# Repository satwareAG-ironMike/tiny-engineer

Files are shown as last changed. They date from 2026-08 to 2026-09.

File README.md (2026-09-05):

# Tiny Engineer

> Give your AI coding agent a body.

Tiny Engineer demo

Tiny Engineer is an open-source, 3D-printable desktop robot that physically acts out what an AI coding agent is doing: reading, thinking, coding, finishing tasks. It runs on an ESP32 over Wi-Fi and exposes a simple REST API, so any tool that can make an HTTP request can drive it.

**[Watch the demo](https://youtu.be/RX_QRxdXMjg) · [Build your own](#build-your-own) · [How it works](#how-it-works) · [API](docs/api.md)**

## Why?

AI coding agents increasingly spend long stretches working on their own. I wanted to see what mine was doing without staring at the IDE.

So I built a slightly ridiculous desk robot: instead of another spinner or status line, there is a tiny teammate sitting next to me, visibly reading, thinking, and typing while the agent works.

## How it works

How Tiny Engineer works

An AI agent works; an integration turns that into events; the robot’s REST API on your LAN receives them; the hardware moves and reacts.

**Two ways in**

- **Built-in** — Cursor Agent → Cursor hooks → `tiny-engineer-cursor` → HTTP over Wi-Fi
- **Bring your own** — Claude, Codex, or any other agent → your script/plugin/app → HTTP REST

Both hit the same Tiny Engineer REST API (`/anim`). The ESP32-C3 runs that API, robot logic, and animations, then drives:

| Bus | Hardware | Role |
| --- | --- | --- |
| I2C | PCA9685 → 5× servos | Head / neck, hands / body |
| I2C | SSD1306 OLED | Status, face, info |
| I2S | MAX98357A → speaker | Audio |

Cursor is one, sample, client, not the architecture. Details: [Cursor hooks](docs/hooks.md) · [any integration](docs/integration.md) · [HTTP API](docs/api.md)

## Build your own

End-to-end path (details live in the linked docs):

New to hardware? Start with **[From Code to Circuits](docs/hardware-for-software-engineers/README.md)** — hardware and electronics for software engineers; Tiny Engineer is the worked example.

1. **Get the electronics** — [hardware inventory](docs/hardware/components.md)
2. **3D print the parts** — [printables](3d_models/README.md)
3. **Assemble the mechanics** — fit the five servos — [3D models](3d_models/README.md), [servo axes](docs/robot-movement.md)
4. **Wire the electronics** — [wiring](docs/hardware/wiring.md), [hardware overview](docs/hardware/README.md)
5. **Flash the ESP32 firmware** — [getting started → Flash](docs/getting-started.md#4-flash)
6. **Configure Wi-Fi** — [getting started → Wi-Fi](docs/getting-started.md#5-wi-fi-setup)
7. **Test the robot** — web UI + a curl — [getting started → Prove it](docs/getting-started.md#6-prove-it)
8. **Connect your coding agent** — [Cursor hooks](docs/hooks.md) or [any IDE / REST](docs/integration.md)

Full walkthrough: [docs/getting-started.md](docs/getting-started.md).

## Hardware overview

Major pieces (exact models and counts in the BOM):

| Role | Part | Qty |
| --- | --- | --- |
| Controller | Waveshare ESP32-C3-Zero | 1 |
| Servo PWM | Adafruit PCA9685 | 1 |
| Actuators | PowerHD HD-1370A micro servos | 5 |
| Display | 0.91" 128×32 SSD1306 OLED (I2C) | 1 |
| Audio | MAX98357A + 8 Ω / 1 W speaker | 1 + 1 |
| USB / power | Adafruit 5993 USB-C breakout; **5 V / ≥2 A** supply | 1 |
| Structure | 3D-printed parts | — |

Complete inventory and limits: [docs/hardware/components.md](docs/hardware/components.md).

## Quick start

Firmware is Arduino on [PlatformIO](https://platformio.org/). From the project root:

```bash
pio run                 # build
pio run -t upload       # flash firmware + LittleFS
pio device monitor      # serial (115200)
```

If servos move but audio is silent, run `pio run -t uploadfs` once.

**Wi-Fi (first boot):** join `TinyEngineer-XXXX`, open `http://192.168.4.1/config`, enter a **2.4 GHz** network. OLED shows the setup steps.

**Web UI:** `http://tiny-engineer.local/` (or the IP on the OLED) — settings, hardware tests, animations.

**Make it move:**

```bash
curl -X POST "http://tiny-engineer.local/anim?name=ring"
```

Full route list: [docs/api.md](docs/api.md). Settings: [docs/settings.md](docs/settings.md).

## AI integrations

Anything that can `POST` over HTTP can drive the robot:

```bash
curl -X POST "http://tiny-engineer.local/anim?name=typing"
```

Useful `name` values: `typing`, `reading`, `thinking`, `ring`, `welcome`, `wakeup`, `sleep`, `attention`, `error`, `abort`, `dead`, `none`.

Cursor projects can map agent events to poses via hooks — [docs/hooks.md](docs/hooks.md). Broader patterns and examples: [docs/integration.md](docs/integration.md).

## Documentation

| Goal | Doc |
| --- | --- |
| Build end-to-end | [docs/getting-started.md](docs/getting-started.md) |
| Parts / BOM | [docs/hardware/components.md](docs/hardware/components.md) |
| Wiring / power | [docs/hardware/README.md](docs/hardware/README.md) |
| Printable parts | [3d_models/README.md](3d_models/README.md) |
| Servo axes / safe ranges | [docs/robot-movement.md](docs/robot-movement.md) |
| HTTP API | [docs/api.md](docs/api.md) |
| Settings | [docs/settings.md](docs/settings.md) |
| Cursor hooks | [docs/hooks.md](docs/hooks.md) |
| Any IDE / REST | [docs/integration.md](docs/integration.md) |
| Full index | [docs/README.md](docs/README.md) |

## Build one, break one, share it

Print it, wire it, change the CAD, swap animations, or hook up a different agent. Issues and PRs welcome — especially new integrations.

Tiny Engineer

## License

- **Software** (firmware, integrations, scripts, documentation) — [MIT](LICENSE)
- **Hardware designs** (CAD source and `.3mf` printables in [`3d_models/`](3d_models/)) — [CERN-OHL-S-2.0](3d_models/LICENSE)

See [LICENSING.md](LICENSING.md) for scope and effective date. The **Tiny Engineer** name and logo are not licensed — see [TRADEMARK.md](TRADEMARK.md).

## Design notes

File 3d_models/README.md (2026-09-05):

# 3D models

Printable parts and source CAD for the Tiny Engineer desk robot.

## Source CAD (edit / resize)

The full assembly — all components composed — lives in [`cad/TinyEngineer.f3d`](cad/TinyEngineer.f3d) (Autodesk Fusion). Open that file to adjust the model or adapt it to different hardware sizing (e.g. different servos).

## Printables

Individual parts are exported to [`parts/`](parts/) as `.3mf` files. They are ready to print in an orientation that does not need supports. Print with **PLA** or **PETG**.

Assembly uses a bunch of **2 mm diameter screws** — no glue. Easy to dismount and modify later. Exact screw lengths/counts and full assembly steps are **not documented yet**. Use the part table below, then electrical and bring-up docs.

## Parts

| File | Role |
| --- | --- |
| `Head.3mf` | Head (pitch) |
| `Neck.3mf` | Neck (yaw) |
| `HandLeft.3mf` | Left hand |
| `HandRight.3mf` | Right hand |
| `Arm.3mf` | Arm (print twice) |
| `Chest.3mf` | Chest / torso |
| `Belly.3mf` | Belly |
| `Chair.3mf` | Chair |
| `Pillow.3mf` | Chair pillow |
| `Desk.3mf` | Desk structure |
| `DeskTop.3mf` | Desk top surface |
| `DeskPad.3mf` | Desk pad |
| `LaptopCase.3mf` | Miniature laptop body |
| `LaptopScreen.3mf` | Laptop screen |
| `Bell.3mf` | Service bell |
| `LampBase.3mf` | Desk lamp base |
| `LampCap.3mf` | Lamp cap |
| `LampGlass.3mf` | Lamp glass |
| `LampButton.3mf` | Lamp button |
| `Mug.3mf` | Mug |
| `MugCoffee.3mf` | Coffee fill |
| `AiEmblem.3mf` | AI emblem detail |

## Next steps

Full build path (print → wire → flash): [docs/getting-started.md](../docs/getting-started.md).

1. Servo axes and safe ranges: [docs/robot-movement.md](../docs/robot-movement.md)
2. Wiring and power: [docs/hardware/wiring.md](../docs/hardware/wiring.md), [docs/hardware/README.md](../docs/hardware/README.md)
3. Bring-up and failures: [docs/hardware/testing.md](../docs/hardware/testing.md)

## License

CAD source (`.f3d`) in [`cad/`](cad/) and printable parts (`.3mf`) in [`parts/`](parts/) are licensed under [CERN-OHL-S-2.0](LICENSE). See [NOTICE](NOTICE) for copyright, Source Location, and product notice requirements.

Commercial use is allowed. If you modify and distribute Products based on these designs, reciprocal provisions require sharing your Complete Source under the same license. This documentation file is software documentation and remains under the MIT License — see [LICENSING.md](../LICENSING.md).

The **Tiny Engineer** name and logo are not licensed — see [TRADEMARK.md](../TRADEMARK.md).

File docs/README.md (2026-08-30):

# Docs index

Pick a path. Depth lives in the linked pages.

| You want to… | Start here |
| --- | --- |
| **Bridge into hardware/electronics** (software engineer background) | [hardware-for-software-engineers/README.md](hardware-for-software-engineers/README.md) |
| **Build from scratch** (parts → print → wire → flash) | [getting-started.md](getting-started.md) |
| **Use with Cursor** (robot already on Wi‑Fi) | [getting-started.md](getting-started.md) → [hooks.md](hooks.md) |
| **Flash / configure** only | [getting-started.md](getting-started.md)#4-flash |
| **Wire / power detail** | [getting-started.md](getting-started.md)#3-wire-and-power → [hardware/README.md](hardware/README.md) |
| **Print / parts inventory** | [getting-started.md](getting-started.md)#2-print-and-mechanical → [../3d_models/README.md](../3d_models/README.md) |
| **HTTP API / settings** | [api.md](api.md); add a setting: [settings.md](settings.md) |
| **Any IDE / scripts** | [integration.md](integration.md) |

Also: [robot-movement.md](robot-movement.md) (servo axes and safe ranges).

**Source of truth:** pin constants in firmware (`include/pins.h`); electrical detail in `docs/hardware/`; HTTP shapes in [api.md](api.md).

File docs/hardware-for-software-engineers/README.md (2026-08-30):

# From Code to Circuits: Hardware for Software Engineers

*Learn electronics and physical builds through Tiny Engineer — a desk robot that's fun to finish and honest about real hardware.*

I wrote this because software engineers keep asking how to build Tiny Engineer when they've never touched the hardware side — what's a servo driver, why two voltages, whether they'll destroy the board on first power-on. The build docs tell you *what to connect*; this guide answers the questions behind them.

---

## Goal

**Bring the world of electronics and hardware closer to software engineers** — especially the ones showing up with Tiny Engineer parts and no hardware background.

If you live in code, hardware docs can feel like a foreign API with no types and no stack traces. This guide closes that gap: same systems thinking you already use — buses, power budgets, failure modes — applied to volts, GPIO, and printed plastic. It's the long-form version of answers I give when someone says *"I'm a developer, I just want the robot to work."*

**Why now:** AI makes writing code fast and cheap. Hardware stays tangible, constrained, and extremely satisfying when something on your desk actually moves because *you* wired it.

**Why Tiny Engineer as the example:** one coherent stack (MCU, I2C, I2S, power domains, 3D print, servos) — real enough to teach honest hardware, bounded enough to finish if you stick with it. It also ties back to software via Wi-Fi and HTTP, which helps the mental bridge.

**What you'll get out of it:** read datasheets, schematics, and embedded docs without feeling like an outsider — whether you build this robot or the next board on your bench.

**Honest expectation:** Tiny Engineer was never meant to be an entry-level electronics kit (no single-LED breadboard tutorial). Overall difficulty is **medium**. It can still be your **first hardware project** as a software engineer — if you read first, bench-test before closing the shell, and don't treat "first" as "trivial." See [difficulty by area](#honest-difficulty-by-area) below.

---

I'm a software engineer. I got into hardware and electronics long before Tiny Engineer — out of curiosity, because I find it fun, and because making something *physical* work hits different from shipping another service. I'm not an EE. I've smelled the regret breadboard too; I've also had plenty of projects since then that actually moved and blinked.

Tiny Engineer is one project in that line. I'd recommend this path to any software engineer: learn the basics, wire something on a bench, watch it do a thing you commanded. Especially now, when a servo buzzes because you misaligned a horn — not because a model hallucinated a pin number — you learn something no codegen session replaces.

**What this is:** a bridge into electronics, microcontrollers, power, protocols, and mechanical build craft — taught with software-engineer mental models.

**What this is not:** only a Tiny Engineer assembly manual. When you're ready to wire and flash step by step, use [getting-started.md](../getting-started.md) and the [hardware reference](../hardware/README.md).

---

## Why Tiny Engineer is the example

Every chapter teaches a **general concept**, then shows **where it lands in this build**. Tiny Engineer gives you real constraints — 3.3 V vs 5 V domains, shared I2C, offloaded servo PWM, print tolerances, antenna keep-out — without throwing you into a parts warehouse with no narrative. Finish the robot if you want the payoff; the vocabulary transfers to other ESP32, Arduino, or IoT projects either way.

It's a good **first hardware project for a software engineer**. It is **not** a good **first project in electronics** in the abstract — compare it to a blinking-LED kit and this is several notches up. This guide exists because those two truths collide constantly in questions from SWEs who want to build the robot anyway.

---

## Honest difficulty by area

Rough levels: **Easy** · **Medium** · **Medium–High** (for someone with no prior hardware builds). Overall build: **Medium**.

| Area | Level | Why |
| --- | --- | --- |
| [Electricity & power domains](01-electricity-and-units.md) | Medium | Two voltage rails, common GND, VCC vs V+ — mistakes fry boards, not just fail tests |
| [Microcontrollers & ESP32](02-microcontrollers-and-esp32.md) | Medium | Wi-Fi MCU, native USB, scarce GPIO, flash/LittleFS — more moving parts than Arduino Uno 101 |
| [Wiring & schematics](03-wiring-craft-and-schematics.md) | Medium–High | Six-ish modules, many nets, classic traps (swapped I2C, speaker on GND) |
| [Buses: I2C, I2S, PWM](04-buses-and-protocols.md) | Medium | Three protocol types in one device; standard hobby stack, but not "one wire one LED" |
| [Servos & mechanical motion](05-servos-and-mechanical-motion.md) | Medium–High | Five joints, horn alignment, mechanical limits, binding/stall — software clamps can't fix physics |
| [3D printing & mechanical build](06-3d-printing-and-mechanical-build.md) | Medium | Many printed parts, tolerances, partial assembly docs; optional Fusion edits add learning curve |
| [Power budgets & safety](07-power-budgets-and-safety.md) | Medium | Real stall currents (~1.3–1.6 A), supply sizing, brownout debugging |
| [Embedded workflow & debug](08-tools-debugging-and-embedded-workflow.md) | Medium *(lower if you live in CLI)* | PlatformIO, serial, bisect bring-up — familiar shape for SWEs, unfamiliar failure modes |
| REST / Wi-Fi / agent hooks | Easy *(for SWEs)* | HTTP you already know — **after** hardware works |

**What makes it medium, not beginner-kit:**
- Multiple ICs on shared buses, not one chip
- Motor power + logic power discipline
- Mechanical assembly with real tolerances
- Debug requires dividing hardware vs software

**What makes it viable as a first SWE hardware project:**
- Documented BOM, wiring, firmware — not a blank breadboard
- Software-shaped affordances: serial logs, HTTP `/test/*`, web UI
- This guide translates concepts into your vocabulary first
- Finish line is motivating (desk robot, not only a blinking LED)

If you've never touched a multimeter, budget extra time on [Ch. 01](01-electricity-and-units.md), [Ch. 07](07-power-budgets-and-safety.md), and bench bring-up in [Ch. 08](08-tools-debugging-and-embedded-workflow.md). Skipping straight to "assemble everything and flash" is how medium projects feel hard.

---

## Who should read this

**Read this if you:**
- Write code for a living and want to build Tiny Engineer (or similar) without a hardware background
- Got the parts or the repo and hit questions the assembly docs don't pause to explain
- Know what HTTP is but not what I2C is
- Can follow a tutorial but want to understand what you're doing
- Are curious about embedded, IoT, or physical computing — even if you've never soldered

**Skip this if you:**
- Already own a multimeter and use words like "pull-up" without Googling
- Have built an ESP32 project before and just need the BOM — go to [getting-started.md](../getting-started.md)

**Don't skip the difficulty section** if this is your first hardware build — [Honest difficulty by area](#honest-difficulty-by-area) sets expectations.

---

## How this fits the rest of the docs

There are three layers. Read them in order when you're learning; jump to the right layer when you know what you need.

```mermaid
flowchart LR
  primer["hardware-for-software-engineers\n(concepts)"]
  build["getting-started.md\n(steps)"]
  ref["hardware/\n(reference)"]

  primer -->|"understand why"| build
  build -->|"look up details"| ref
```

| Layer | When to use it |
| --- | --- |
| **This guide** | Bridging hardware/electronics concepts from a software background |
| **[getting-started.md](../getting-started.md)** | Doing the build step by step |
| **[hardware/](../hardware/README.md)** | Looking up pins, wiring, power numbers, test procedures |

---

## Reading order

**Full path** (recommended if hardware is new to you):

1. [Electricity and units](01-electricity-and-units.md)
2. [Microcontrollers and ESP32](02-microcontrollers-and-esp32.md)
3. [Wiring craft and schematics](03-wiring-craft-and-schematics.md)
4. [Buses and protocols](04-buses-and-protocols.md)
5. [Servos and mechanical motion](05-servos-and-mechanical-motion.md)
6. [3D printing and mechanical build](06-3d-printing-and-mechanical-build.md)
7. [Power budgets and safety](07-power-budgets-and-safety.md)
8. [Tools, debugging, and embedded workflow](08-tools-debugging-and-embedded-workflow.md)
9. [How it all fits together](09-how-it-all-fits-together.md)

**Shortcuts** — where universal concepts land in this build; jump to one chapter if you only need that topic:

| You need to understand… | Read |
| --- | --- |
| ESP32-C3-Zero, GPIO, USB, antenna | [Ch. 02](02-microcontrollers-and-esp32.md) |
| 3.3 V vs 5 V, LDO, VCC vs V+ | [Ch. 01](01-electricity-and-units.md) + [Ch. 07](07-power-budgets-and-safety.md) |
| I2C (OLED + PCA9685) | [Ch. 04](04-buses-and-protocols.md) |
| I2S (audio) | [Ch. 04](04-buses-and-protocols.md) |
| Servo PWM chain | [Ch. 04](04-buses-and-protocols.md) + [Ch. 05](05-servos-and-mechanical-motion.md) |
| Fusion CAD edits | [Ch. 06](06-3d-printing-and-mechanical-build.md) |
| PLA vs PETG | [Ch. 06](06-3d-printing-and-mechanical-build.md) |

---

## Mini glossary

Terms you'll see everywhere. Each chapter goes deeper. Think of these as hardware concepts translated into software-shaped words.

| Term | One-line meaning |
| --- | --- |
| **MCU** | The chip that runs your firmware — like a tiny server that boots straight into one binary (no OS, no SSH). Here: ESP32-C3 |
| **GPIO** | A pin the firmware can drive or read — hardware I/O endpoints, not USB or Wi-Fi |
| **GND** | Shared **0 V reference** for every module — like agreeing on one clock/time base; without it, nothing can talk reliably |
| **3.3 V / 5 V** | **Signal voltage** (3.3 V, ESP32-safe) vs **power rail** (5 V, servos/amp) — two different numbers; don't mix them up |
| **LDO** | Onboard **5 V → 3.3 V converter** for logic chips — sized for milliamps, not motors |
| **I2C** | Two-wire **request/response bus** — each chip has an address (`0x40`, `0x3C`); ESP32 is the only master |
| **I2S** | **Streaming audio bus** — continuous PCM samples over wires, like a one-way socket, not I2C-style reads |
| **PWM** | A pin toggling on/off on a schedule — servos read **pulse length** inside each cycle as "go to this angle" |
| **Brownout** | Power sags → chip **hard-resets** — feels like a random reboot, often when servos or audio spike current |
| **PCA9685** | **Servo PWM co-processor** — ESP32 sends angles over I2C; this chip generates the precise 50 Hz pulses |

---

## When you're ready to build

You've read enough when you can explain in plain language:

- Why servos don't get power from the ESP32's 3.3 V pin
- What I2C and I2S do on this robot (and that they're different)
- Why there's a separate PCA9685 chip instead of "just PWM in code"
- Where the ceramic antenna is and why you shouldn't bury it in plastic

Then open [getting-started.md](../getting-started.md) and work through parts → print → wire → flash → Wi-Fi → prove it.

**Reference:** [getting-started.md](../getting-started.md) · [hardware/README.md](../hardware/README.md) · [3d_models/README.md](../../3d_models/README.md)

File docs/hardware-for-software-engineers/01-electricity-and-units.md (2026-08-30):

# Electricity and units

Before you touch a wire, you need a shared vocabulary. Hardware docs throw around V, A, Ω, and GND like everyone took a circuits class. You didn't — that's fine. This chapter gets you to "I know what could kill my board." Every embedded project has power rails and a common ground; Tiny Engineer is a clear example of **two voltage domains** on one USB cable.

---

## Voltage, current, resistance, power

Four quantities. You'll see them on every datasheet.

| Quantity | Unit | What it means (intuition) |
| --- | --- | --- |
| **Voltage (V)** | Volts | Electrical "pressure" — how hard electrons are being pushed |
| **Current (I)** | Amperes (amps) | Flow rate — how many electrons per second |
| **Resistance (R)** | Ohms (Ω) | How much something resists flow |
| **Power (P)** | Watts (W) | Energy used per second — P ≈ V × I |

> **If you've written backend code…** Voltage is like request pressure on a queue. Current is throughput. Resistance is backpressure. Power is your AWS bill when both spike at once.

**Ohm's law** (you don't need to derive it): V = I × R. If you push harder (more V) through the same resistance, more current flows. Thin wire = more R = less I for the same V.

---

## DC vs AC

**DC (direct current):** voltage stays one way, like a battery. Tiny Engineer runs on **5 V DC** from USB.

**AC (alternating current):** voltage flips direction — wall outlets, 50/60 Hz. Not relevant inside the robot except that your USB charger converts AC to DC before the robot ever sees it.

---

## What "ground" (GND) actually is

GND is not a magical sink into the earth. It's a **shared reference point** that every device agrees is "zero volts."

All signals are measured *relative to GND*. If two boards don't share GND, their "high" and "low" mean nothing to each other — like two services with no common schema.

**Rule:** Connect all GND pins together. One common ground net for the whole robot.

---

## Series and parallel (just enough)

**Series:** components in a chain — same current flows through all of them.

**Parallel:** components side by side — same voltage across each branch; current splits.

Your five servos are **parallel** on the 5 V rail: each gets 5 V, and current adds up. That's why five servos can pull ~1.3 A together and overwhelm a weak USB port.

---

## Shorts, reversed polarity, and smoke

Three ways beginners destroy boards. Each is a **wiring mistake**, not a firmware bug — the code may never run.

### Short circuit — power wired straight to ground

**What it is:** `+5V` and `GND` connected with **almost no resistance** between them — a bare wire, a loose strand, a metal tool, a solder bridge.

**What happens:** Current spikes (Ohm's law: low R → huge I). Wires heat. USB port or regulator shuts off — or something burns. The chip may die instantly.

**What it looks like:** Instant. Sometimes smell. Board never boots. Multimeter beep between 5V and GND *before* power-on = stop and fix wiring.

> **Software analogy:** Like routing all traffic to `/dev/null` with infinite concurrency — the system doesn't degrade gracefully; something upstream trips hard.

**Common causes while wiring:** twisted red/black leads, frayed insulation, screwdriver slip, VCC accidentally tied to GND on a breakout.

### Reversed polarity — + and − swapped

**What it is:** Power connected **backwards** — positive where ground should be, ground where positive should be.

**What happens:** Depends on the board. Some breakouts have protection diodes; many don't. Best case: nothing until you fix it. Worst case: dead regulator, dead MCU, dead module.

**Rule:** Match labels on the diagram (`5V`, `VCC`, `Vin`, `GND`). Red-ish often means positive; black/brown often means ground — **verify**, don't guess from habit alone.

> **Don't "test" reversal on purpose.** Fix orientation before first power-on.

### Logic overvoltage — 5 V on a 3.3 V GPIO pin

**What it is:** Driving **5 V into an ESP32 GPIO** that only tolerates **3.3 V**. Different from powering the whole board at 5 V through its proper **5V** input pad (that path goes through the onboard regulator).

**What happens:** Input protection may clamp once; repeated or sustained overvoltage **damages the pin or the chip**. Behavior becomes erratic; pin may die silently.

**On Tiny Engineer:** I2C, I2S, and servo **signal** lines are 3.3 V logic. Servo **motor power** is 5 V on the red wire — that goes to PCA9685 **V+**, not to an ESP32 GPIO.

> **Software analogy:** Sending a payload the parser never validated — undefined behavior, often permanent. No try/catch on the silicon.

### Quick reference

| Mistake | You literally did | Typical result |
| --- | --- | --- |
| **Short** | Connected +5V to GND directly | Huge current, heat, dead supply path or board |
| **Reversed polarity** | Swapped power + and − on a module | Dead module or MCU — may be instant |
| **Logic overvoltage** | 5 V signal into ESP32 GPIO / 3.3 V input | Damaged pin or chip — flaky then dead |

**Before first power-on:** visual check, then continuity test (power **off**) — no beep between 5V and GND; every module's GND tied together. Assembly checks: [wiring.md](../hardware/wiring.md).

---

## 3.3 V, 5 V, and ones and zeros

In code you think in **bits**: `0` and `1`, `true` and `false`, `LOW` and `HIGH`. On a GPIO pin that is **not abstract** — the chip **holds the wire at a voltage** relative to GND:

| Logic (firmware) | Typical voltage on ESP32 pin | Meaning |
| --- | --- | --- |
| **0** / `LOW` / `false` | ~**0 V** (near GND) | "Pull the line down" |
| **1** / `HIGH` / `true` | ~**3.3 V** | "Pull the line up" |

So **3.3 V is the "one" voltage** on this robot's logic wires. A **zero** is not a separate negative voltage — it's "close enough to ground."

> **If you've written backend code…** GND is 0.0; a logic **1** is ~3.3 — like a boolean with a defined numeric encoding on the wire. I2C and I2S don't send JSON; they toggle and stream voltages that the other chip interprets as bits.

### Two different jobs — don't confuse them

| | **3.3 V (logic domain)** | **5 V (power domain)** |
| --- | --- | --- |
| **Role** | Encode **0s and 1s**; run logic chips at their rated voltage | **Deliver energy** — motors, audio amp, board power input |
| **On Tiny Engineer** | ESP32 GPIO, I2C (SDA/SCL), I2S (BCLK/LRC/DIN), servo **signal** wires, **VCC** on PCA9685/OLED | Servo **motor** power (red wire → PCA9685 **V+**), MAX98357A **Vin**, ESP32 **5V** input pad |
| **Current** | Milliamps per pin / tens of mA on a **VCC** rail | Up to **~1.5 A** when servos stall |

**VCC** on a breakout (3.3 V) = "power this chip's brain so it can read and drive ones and zeros." It is **not** the same net as the 5 V that spins a servo.

**5V** on the ESP32 board = "feed the module" — an onboard **LDO** drops that to 3.3 V so the chip's core and GPIO speak the right logic levels.

### What goes wrong if you mix them up

- **5 V on a GPIO / I2C / I2S line** — you're forcing a **"one" louder than the chip allows** (~3.3 V max on ESP32). Damage. See **Logic overvoltage** above.
- **Servo motor power from 3.3 V** — the line can't supply enough **current** to move metal; brownout or dead regulator. Signal wire at 3.3 V PWM is fine; **power** wire needs 5 V.

When you read `digitalWrite(pin, HIGH)` in firmware, picture **~3.3 V on that pin**. When you read a schematic's **3V3** net, picture **the rail that defines what a "one" looks like** for every chip tied to it.

---

## Two voltage domains (the idea)

Real boards rarely run everything at one voltage. You'll see:

- A **power rail** (often 5 V) for things that need muscle — motors, amplifiers
- A **logic rail** (3.3 V) where **ones and zeros live** — GPIO, I2C, I2S, chip **VCC**

They share GND (that's your **zero**). They do **not** share the same positive rail unless a regulator explicitly converts between them.

---

## In Tiny Engineer

This robot is a textbook example of **two domains on one USB cable**.

```mermaid
flowchart TB
  USB["USB 5V"]
  subgraph fiveV [5V domain]
    ESP5[ESP32 5V in]
    PCApwr[PCA9685 5V and V+]
    MAXvin[MAX98357A Vin]
    SERVOS[Servo motors]
  end
  subgraph threeV [3.3V logic domain]
    ESPcore[ESP32 GPIO and core]
    PCAlogic[PCA9685 VCC]
    OLED[OLED VCC]
  end
  USB --> fiveV
  ESP5 --> ESPcore
  ESPcore --> threeV
  PCApwr --> SERVOS
```

**5 V domain** — USB comes in through the Adafruit 5993 breakout and feeds:
- ESP32 **5V** input (then an onboard LDO drops to 3.3 V for the chip)
- PCA9685 **5V** and **V+** (servo motor power)
- MAX98357A **Vin** (audio amp)

**3.3 V domain** — the ESP32's LDO generates the rail where **logic 1 = ~3.3 V** and **logic 0 = ~0 V**:
- ESP32 core and GPIO (your `HIGH` / `LOW` in code)
- PCA9685 **VCC** (chip logic + I2C — reads 0/1 on SDA/SCL)
- OLED **VCC** (display logic on the same I2C bus)

### The mistake that costs boards

The PCA9685 has **VCC** (3.3 V logic) and **V+** (5 V servo power). They must stay **separate**. Beginners jumper them because both say "power." Don't. You feed motor current into logic circuits or starve servos of voltage.

### Never power servos from 3.3 V

Five HD-1370A servos at stall draw on the order of **1.3–1.6 A**. The ESP32's LDO is rated for hundreds of mA of *logic*. Plug servos into 3.3 V and you get brownout, reset, or a dead regulator. Servos get 5 V via PCA9685 **V+**; the signal wire is 3.3 V PWM from the driver — that's fine.

### Common GND

Every module — ESP32, PCA9685, OLED, amp, servos — ties GND to the same net. Power without shared GND is like deploying microservices that can't reach each other's network.

Full stall math and symptom tables: [power.md](../hardware/power.md).

---

**Next:** [Microcontrollers and ESP32](02-microcontrollers-and-esp32.md)

**Reference:** [hardware/power.md](../hardware/power.md) · [hardware/wiring.md](../hardware/wiring.md)

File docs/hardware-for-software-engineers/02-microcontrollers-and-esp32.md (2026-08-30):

# Microcontrollers and ESP32

Your laptop runs Linux, Chrome, and seventeen Slack notifications. A microcontroller runs *one program*, forever, with no OS you recognize. That gap — between "real computer" and "chip that drives GPIO" — is where most software engineers stall. This chapter closes it. Tiny Engineer uses an **ESP32-C3** as its instance; the ideas apply to Arduino, STM32, and most hobby boards.

---

## MCU vs SBC vs your laptop

| | Microcontroller (MCU) | Single-board computer (SBC) | Laptop |
| --- | --- | --- | --- |
| Examples | ESP32, Arduino, STM32 | Raspberry Pi, BeagleBone | What you're reading this on |
| OS | Bare-metal or RTOS; often "Arduino" | Full Linux | Full OS |
| Boot time | Milliseconds | Seconds | Minutes if updates pending |
| GPIO pins | Yes, direct | Yes, but often through OS layers | Basically no |
| Real-time I/O | Designed for it | Possible, awkward | Not the point |
| Power | Milliwatts to low watts | Watts | Tens of watts |

Tiny Engineer needs Wi-Fi, five servos, a display, and audio on a desk robot budget. An MCU with built-in radio fits. A Pi would work but adds OS overhead, boot time, and power for no gain here.

---

## What firmware is

**Firmware** is the program stored in flash on the chip. It runs on boot. There's no `git pull` on the device — you **build** on your computer and **upload** (flash) the binary over USB.

> **If you've written backend code…** Flashing firmware is deploying a single static binary to a device with no package manager. Serial monitor is `stdout`. There's no SSH — you re-flash or use HTTP once Wi-Fi works.

**Flash** = non-volatile storage (survives power-off). Holds your program and, on this project, LittleFS files (WAV sounds).

**RAM** = working memory. Much smaller than flash. Gone on reboot.

---

## GPIO — the hardware API

**GPIO** (General Purpose Input/Output) pins are wires the firmware controls or reads. On the wire that is literally **zeros and ones** as voltages (see [Ch. 01](01-electricity-and-units.md)):

- **Output HIGH / 1** ≈ 3.3 V on that pin (on ESP32)
- **Output LOW / 0** ≈ 0 V (GND)
- **Input** — read whether the other side is holding the line high or low

Blink an LED? Firmware toggles one pin between 0 and 1. Same idea scales up: **communication protocols are patterns of zeros and ones on one or more pins over time** — serial (UART), I2C, SPI, I2S, even USB on this chip. Libraries hide the bit timing; underneath it's still GPIO-level signaling.

You don't get unlimited pins. Each pin might be reserved for flash, USB, or boot strapping. Scarcity is real — see [pinout.md](../hardware/pinout.md) for the full map.

---

## Boot, reset, and upload

**RESET** — reboots the chip (like killing and restarting a process).

**BOOT** — strapping pin; hold during reset to enter serial upload mode if auto-reset fails.

**Upload** — PlatformIO sends firmware over USB. On ESP32-C3, that's **native USB** on specific GPIO pins (not a separate USB-UART chip).

If upload fails: try another cable (data, not charge-only), another port, hold BOOT, check drivers. Details in [getting-started.md § Flash](../getting-started.md#4-flash).

---

## What "Arduino on ESP32" means

This project uses **PlatformIO** with the **Arduino framework** for ESP32. You get `setup()` / `loop()`, familiar libraries (`Wire` for I2C, etc.), and Espressif's Wi-Fi stack underneath.

You're not writing bare-metal RISC-V assembly. You're writing C++ that compiles to a binary the chip runs directly. `platformio.ini` picks the board target and libraries.

---

## ESP32 family (just enough context)

Espressif makes many ESP32 variants. Tiny Engineer uses **ESP32-C3**:

- **RISC-V** single-core (not the older dual-core Xtensa ESP32)
- **Wi-Fi 2.4 GHz only** — no 5 GHz; your router must expose 2.4 GHz for setup
- **BLE** exists on the silicon; this project's firmware doesn't use it
- Native **USB** — no external CP2102 required when wired correctly

---

## In Tiny Engineer

### The board: Waveshare ESP32-C3-Zero

Not a generic breadboard devkit. It's a compact module with castellated edges, a ceramic antenna, and an onboard RGB LED.

**PlatformIO naming trap:** `board = esp32-c3-devkitm-1` in `platformio.ini` is a **build target name**, not the physical board in your hand. The physical board is the C3-Zero. Same chip, different pin breakout — the project's [pinout.md](../hardware/pinout.md) and [components.md](../hardware/components.md) describe *this* board.

### What the ESP32 does here

| Job | How |
| --- | --- |
| Wi-Fi + HTTP API | Agent integration, web UI, `/anim`, `/test/*` |
| I2C master | Talks to PCA9685 (servos) and OLED (display) |
| I2S master | Streams audio samples to MAX98357A |
| Status RGB | Onboard WS2812 on GPIO10 — boot green, anim white, error red |
| "Sensor" | On-die CPU temperature in `/health` — that's it, no IMU |

### Pins you'll hear about (conceptual)

The firmware dedicates most exposed GPIOs. Rough mental map:

- **GP0 / GP1** — I2C (SDA / SCL) to PCA9685 and OLED
- **GP2–GP4** — I2S (BCLK, LRC, DIN) to audio amp
- **GP9** — BOOT button
- **GP10** — onboard RGB LED
- **GP18 / GP19** — native USB D− / D+ (wired to Adafruit 5993 breakout when assembled)

Many other GPIOs are used internally for flash and aren't available. Don't reassign USB pins if you flash over that cable.

Full allocation: [pinout.md](../hardware/pinout.md).

### USB: onboard vs breakout

The C3-Zero has a USB-C port on the board, but **when the robot is assembled**, flash and serial go through the **Adafruit 5993 USB-C breakout** wired to GPIO18/19. One cable on the robot's exterior for power and programming.

### The RGB LED is your boot log

Before Wi-Fi works, the LED tells you state: dim green while booting, solid red if init failed (e.g. PCA9685 missing). It's the hardware equivalent of a health-check endpoint you can see without serial.

### Ceramic antenna — don't bury it

Wi-Fi is how coding agents talk to the robot. The C3-Zero uses a **ceramic antenna** on the board. Metal or thick plastic pressed against it kills range. When you design or assemble the shell, leave a keep-out zone. More in [Ch. 06](06-3d-printing-and-mechanical-build.md).

### Flash workflow

Build, upload, monitor — copy-paste lives in [getting-started.md § Flash](../getting-started.md#4-flash). This chapter stops at *what* the chip is; that page is *how* to deploy.

---

**Next:** [Wiring craft and schematics](03-wiring-craft-and-schematics.md)

**Reference:** [hardware/components.md](../hardware/components.md) · [hardware/pinout.md](../hardware/pinout.md) · [getting-started.md § Flash](../getting-started.md#4-flash)

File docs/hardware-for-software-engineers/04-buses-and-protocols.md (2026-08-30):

# Buses and protocols

GPIO pins output **zeros and ones** as voltages ([Ch. 02](02-microcontrollers-and-esp32.md)). A **protocol** is a schedule for those bits over time — same idea as a wire format, just on copper.

This robot uses four. **I2C and I2S look like cousins in the name. They are not.** I2C is request/response to chips with addresses. I2S is a one-way audio stream. Mix them up and nothing talks.

| Protocol | Pattern | On this robot |
| --- | --- | --- |
| **I2C** | Request/response, addressed devices | PCA9685 + OLED |
| **I2S** | Continuous audio stream | MAX98357A amp |
| **PWM (servo)** | Timed HIGH pulse = angle | PCA9685 → servos |
| **USB** | Power + serial data | Flash, monitor, 5 V in |

```mermaid
flowchart TB
  ESP[ESP32-C3]
  ESP -->|I2C| PCA[PCA9685]
  ESP -->|I2C| OLED[OLED]
  ESP -->|I2S| AMP[MAX98357A]
  PCA -->|PWM 50Hz| SRV[Servos]
  AMP --> SPK[Speaker]
```

Pin numbers and timing: [interfaces.md](../hardware/interfaces.md).

---

## I2C — REST on two wires

**I2C** uses two shared wires:

- **SDA** — data
- **SCL** — clock (who talks when)

Many chips hang on the **same** two wires. Each has an **address** (a device ID). The ESP32 is the only **master**: "hey `0x40`, write these bytes." One chip answers.

Idle, both wires sit **HIGH** (logic 1). Devices talk by pulling a line **LOW**. The PCA9685 and OLED boards already include the resistors that hold idle HIGH — you don't add extra ones here.

> **If you've written backend code…** I2C is a shared message bus with explicit IDs. One master. Like REST: you address a host, send a payload, wait for an ACK. No answer ≈ 404 — often a swapped wire or a dead rail, not a bug in your JSON.

**On this robot:** GPIO0 = SDA, GPIO1 = SCL.

| Device | Address | If missing |
| --- | --- | --- |
| PCA9685 (servo driver) | `0x40` | **Fatal** — red RGB, firmware hangs |
| SSD1306 OLED | `0x3C` | **Soft fail** — robot works, no display |

PCA9685 is load-bearing. OLED is nice-to-have for bring-up.

**Traps:**
- SDA/SCL swapped → nothing works
- OLED pad labeled **SCK** is I2C **SCL**, not SPI clock
- "Device not found" *after* servos start moving → often **power sag**, not a bad bus. See [Ch. 07](07-power-budgets-and-safety.md)

---

## I2S — a streaming socket for sound

**I2S** (Inter-IC Sound) pushes **audio samples** continuously. Not "read register, get byte" like I2C.

Three lines from ESP32 to the amp:

- **BCLK** — bit clock (how fast bits move)
- **LRC** (also called WS) — which sample slot this is (left/right)
- **DIN** — the actual bits

ESP32 is master: it generates clocks and **pushes**. The MAX98357A receives and drives the speaker. You don't query the amp for the next sample.

> **If you've written backend code…** I2C is REST. I2S is a one-way socket pumping PCM. While audio plays, samples go out at 44100 Hz until you stop.

Firmware here: **44100 Hz**, 16-bit. Amp is mono; firmware writes the same sample to both stereo slots. Extra amp pins (GAIN, SD) are unwired — the breakout's defaults apply.

**Trap:** speaker connects **SPK+** to **SPK−** only. **SPK− is not GND.** Tying it to ground can damage the amp. #1 audio wiring mistake.

More: [interfaces.md](../hardware/interfaces.md) · [components.md](../hardware/components.md).

---

## PWM — how long HIGH lasts is the angle

**PWM** (Pulse Width Modulation) means: pin goes **HIGH** (1), then **LOW** (0), over and over.

Hobby **position servos** don't care about "what percent of the time it's on." They measure **how long the HIGH pulse lasts** each cycle.

They expect about **50 repeats per second** (a 20 ms window). Inside that window, a HIGH of roughly **1–2 ms** sets the angle. Neutral is typically ~1.5 ms. The servo measures **time**, not voltage.

Firmware maps 0–180° to **800–2200 µs** ([servos.md](../hardware/servos.md)). Mechanical safe ranges are tighter — [robot-movement.md](../robot-movement.md).

**Why a PCA9685:** Wi-Fi + I2S + five servos on one chip makes timing jitter. The PCA9685 is a **PWM worker**: ESP32 sends an angle over I2C; the chip keeps emitting a clean 50 Hz pulse.

**Three wires per servo:**
- **SIG** — PWM (3.3 V zeros and ones from the PCA9685)
- **+5 V** — motor power from PCA9685 **V+** (not ESP32 3.3 V)
- **GND** — common ground

```mermaid
flowchart LR
  HTTP["POST /test/servo"]
  FW["Firmware angle clamp"]
  I2C["I2C to PCA9685 0x40"]
  PWM["50 Hz PWM ch 0-4"]
  SRV["HD-1370A servos"]
  HTTP --> FW --> I2C --> PWM --> SRV
```

Joints and horns: [Ch. 05](05-servos-and-mechanical-motion.md).

---

## USB — one cable, two jobs

USB-C (Adafruit 5993 breakout) does:

- **5 V power** — feeds the whole robot
- **D+ / D−** — native USB to the ESP32 for flash and serial (`stdout`)

Not USB-PD conversion: it does **not** turn 9/12/20 V into 5 V. Feed a normal 5 V USB supply. Current limit: [Ch. 07](07-power-budgets-and-safety.md).

---

## Recap

| | Pattern | This robot | Typical mistake |
| --- | --- | --- | --- |
| **I2C** | Request/response + addresses | PCA9685 + OLED (GP0, GP1) | Swapped SDA/SCL; OLED SCK ≠ SPI |
| **I2S** | Continuous PCM stream | Amp (GP2–GP4) | SPK− tied to GND |
| **PWM** | HIGH pulse length = angle | PCA9685 → five servos | Powering servos from 3.3 V |
| **USB** | Power + serial | 5993 → 5 V + flash | Charge-only cable; expecting PD |

You'll never route I2S to the OLED. Similar names, different jobs.

---

**Next:** [Servos and mechanical motion](05-servos-and-mechanical-motion.md)

**Reference:** [hardware/interfaces.md](../hardware/interfaces.md) · [hardware/servos.md](../hardware/servos.md) · [api.md](../api.md)

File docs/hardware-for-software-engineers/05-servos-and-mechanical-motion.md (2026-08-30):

# Servos and mechanical motion

**Position servos** are everywhere in hobby robotics — small actuators that go to an angle and hold. They're not stepper motors, not DC gearmotors. Understanding them saves you from stripped gears and firmware angles that mean nothing physically. Tiny Engineer has **five** of them; the mechanics chapter applies to any servo-driven joint.

---

## What a hobby servo is

A **position servo** (specifically the **PowerHD HD-1370A** micro servos in this build) contains:

- Motor
- Gear train
- Potentiometer (position feedback)
- Control board that compares commanded pulse width vs actual angle

You command an **angle** (via pulse width). The servo tries to reach it and **holds** there — even against light load.

**Not** continuous rotation — it stops at mechanical limits (~130° usable on these units, marketed sometimes as 180°).

**Three wires:**
| Wire | Role |
| --- | --- |
| Signal (SIG) | PWM in — angle command |
| +5 V (red) | Motor power |
| GND (brown/black) | Common ground |

Power and signal are separate. The signal wire is low current; the power wire carries motor current.

PWM here means a timed HIGH pulse on the signal wire — how long that HIGH lasts is the angle. Full protocol picture (and why a PCA9685 does it): [Ch. 04 — Buses and protocols](04-buses-and-protocols.md#pwm--how-long-high-lasts-is-the-angle).

---

## PWM as angle — recap

Short version (details in [Ch. 04](04-buses-and-protocols.md#pwm--how-long-high-lasts-is-the-angle)): ~50 Hz frame, pulse width sets target:

- ~1500 µs ≈ center / neutral
- Shorter pulse → one direction
- Longer pulse → other direction

Firmware maps 0–180° to **800–2200 µs** on this project. That's the *electrical* range. The *mechanical* range in the assembled robot is narrower — see below.

---

## Horns, splines, and alignment

On this robot (and most 3D-printed hobby builds) the **servo body sits in a printed pocket** — screws or a tight fit, not a metal bracket. The printed part *is* the mount. The moving piece is whatever is on the **output shaft**.

**Spline** — toothed shaft on the servo. **Horn** — the small plastic arm (or a printed piece that mates the same teeth) that locks onto that spline. Teeth only line up in discrete steps — one tooth off and the rest pose is wrong.

**Typical order:**
1. Seat the servo in the printed pocket (don't force — reprint or ream if it's a press-fit from hell)
2. Power to **center** (firmware boot centers slowly on purpose)
3. Press the horn / printed lever onto the spline at the **neutral pose** for that joint (hand down, head looking at the laptop, etc.)
4. Horn screw from the servo bag — snug, not stripped

The printed pocket holds the **case**. The horn (or printed horn-shaped part) transfers **rotation** into the next printed piece. Misalign the spline and the hand hits the desk at "90°" in firmware.

**Off-by-one spline** — one tooth wrong → rest pose crooked → you clamp in software until you hit a printed stop and gears slip.

> **If you've written backend code…** Horn alignment is the zero offset. Wrong offset corrupts everything downstream. Software clamps don't fix a printed stop.

---

## Mechanical limits vs firmware limits

Two layers of limits:

| Layer | What limits | Where defined |
| --- | --- | --- |
| **Electrical** | 800–2200 µs pulse | Firmware constants |
| **Mechanical** | Horn hits shell, linkage binds, servo stalls | Your assembly |
| **Safe software** | Clamped angles per joint | `SERVO_SPECS` in firmware |

Always respect **safe ranges** for the assembled robot — [robot-movement.md](../robot-movement.md). Bench-only wider sweeps (75–105°) exist for testing; don't slam full electrical range into a built shell.

**Tune after assembly:** if a hand hits the desk at 135°, lower `max` in firmware or reorient the horn — don't "just command less" in one script and forget.

---

## Backlash, binding, stall

**Backlash** — gear slack; small commanded moves may not visibly move until slack is taken up. Normal at micro scale.

**Binding** — linkage too tight, screw into moving path, printed hole too small. Servo buzzes, draws stall current, gets hot.

**Stall** — servo commanded past mechanical stop. High current (~260–320 mA per servo at stall). Five servos stalling together browns out the board. Hear buzzing? Stop commanding into the stop.

---

## The Tiny Engineer servo stack

End-to-end path from HTTP to motion:

```mermaid
flowchart LR
  HTTP["POST /test/servo"]
  FW["Firmware angle clamp"]
  I2C["I2C to PCA9685 0x40"]
  PWM["50 Hz PWM ch 0-4"]
  SRV["HD-1370A servos"]
  HTTP --> FW --> I2C --> PWM --> SRV
```

1. You hit `/test/servo` or an animation (see [api.md](../api.md))
2. Firmware clamps angle to `SERVO_SPECS` safe range for that joint
3. I2C write to PCA9685 at address `0x40`
4. Chip outputs 50 Hz PWM on channel 0–4
5. Servo moves

**Channel → joint mapping** (names only — angles in [robot-movement.md](../robot-movement.md)):

| Channel | Joint | Motion |
| --- | --- | --- |
| 0 | Head | Pitch (nod) |
| 1 | Neck | Yaw (turn) |
| 2 | Left hand | Up/down |
| 3 | Right hand | Up/down |
| 4 | Body | Torso twist |

### Left vs right hand — inverted scale

The left and right hand servos mirror each other physically. Firmware uses **opposite angle mapping**: on the left, higher angle = up; on the right, higher angle = down. Rest pose for "typing" uses left at max, right at min.

Symmetric code, asymmetric hardware — normal in robots.

### Boot centering — slow on purpose

On boot, servos move to center at **35°/s** (`SERVO_BOOT_SPEED_DEG_S`), not full speed. Sudden jumps on power-up strip gears and scare you. Live motion can be faster — see [servos.md](../hardware/servos.md).

### PCA9685 is required

No PCA9685 at `0x40` → init fails, red LED, hang. Unlike the OLED. Plan bring-up accordingly.

---

## Bench testing before closing the shell

1. Mount one servo in loose fixture or hand-hold (careful — pinching)
2. Flash firmware, verify serial shows PCA9685 OK
3. Command one joint via web UI or `/test/servo`
4. Sweep through **safe range** slowly — watch for binding
5. Repeat for all five before screwing into final plastic

Mechanical integration last. Software can clamp angles; it can't un-strip a gear.

---

**Next:** [3D printing and mechanical build](06-3d-printing-and-mechanical-build.md)

**Reference:** [robot-movement.md](../robot-movement.md) · [hardware/servos.md](../hardware/servos.md) · [api.md](../api.md)

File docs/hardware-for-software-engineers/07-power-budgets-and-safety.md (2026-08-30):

# Power budgets and safety

Software crashes give you a stack trace. Power problems give you "it worked until I ran an animation" and random reboots. This chapter is capacity planning for electrons — any design that pairs a microcontroller with motors or audio will hit the same wall. Tiny Engineer's five servos make the math honest.

---

## Why the supply rating matters

A USB charger label says **5 V / 2 A**. That's a promise of voltage and *maximum* current the source can sustain.

Every load draws what it needs (not what the label says). **Current adds in parallel:**

- ESP32 + Wi-Fi TX — tens to hundreds of mA peaks
- OLED + PCA9685 logic — tens of mA
- MAX98357A + speaker — peaks on loud WAV
- **Five servos** — **~1.3–1.6 A** if several stall together (HD-1370A datasheet)

A **1 A phone charger** is not enough. Recommendation: **5 V / ≥ 2 A**, with margin if servos move during audio.

---

## Stall current — worst-case load test

A **stall** is when the motor tries to move but can't — horn against stop, binding linkage, desk collision.

Per HD-1370A datasheet (approximate):

| Condition | Per servo | × 5 servos |
| --- | --- | --- |
| Stall @ ~4.8 V | ~260 mA | **~1.3 A** |
| Stall @ ~6.0 V | ~320 mA | **~1.6 A** |

Robot rail is ~5 V — expect something in between if multiple servos stall at once.

That's **before** Wi-Fi, display, and audio peaks.

> **If you've written backend code…** Stall current is your load test at 100× traffic. The supply must survive it or the whole service restarts (brownout).

---

## Tiny Engineer power budget story

Walk through a bad scenario:

1. Robot on a **1.5 A** USB port (5993 breakout advertises up to ~1.5 A via CC resistors — actual delivery depends on the charger)
2. Animation commands three servos at once
3. Wi-Fi transmits HTTP response
4. WAV plays through MAX98357A
5. Rail sags below ESP32 brownout threshold
6. **Reset** — looks like firmware bug; serial shows boot loop

**Symptom map:**

| Symptom | Often actually |
| --- | --- |
| Reset when servos start | Insufficient 5 V current |
| Servo jitter / weak torque | Sagging rail or thin power wires |
| OLED blank / glitch during motion | Power or I2C glitch from sag |
| I2C NACK after motion | Brownout side effect, not bad address |
| Audio crackle on loud sounds | Rail dip under combined load |

Full numbers and architecture: [power.md](../hardware/power.md).

---

## VCC vs V+ (again, because it burns boards)

On PCA9685:

| Pin | Voltage | Powers |
| --- | --- | --- |
| **VCC** | 3.3 V | Chip logic, I2C |
| **V+** | 5 V | Servo motor rail |

Jumpering them = wrong domain crossover. See [Ch. 01](01-electricity-and-units.md).

**Never** power servos from ESP32 **3V3** — LDO is for logic, not ~1.5 A of motors.

---

## USB-C breakout (5993) — what it does and doesn't do

**Does:**
- Bring USB-C connector to your wiring
- Pass **5 V** and **GND**
- Route **D+ / D−** to ESP32 for flash/serial
- Advertise ~1.5 A sink via CC resistors

**Does not:**
- Convert USB-PD 9/12/20 V down to 5 V
- Create current — only passes what the upstream charger provides

Weak laptop port or thin cable → voltage drop → mystery failures. Use a known-good **2 A** brick and a **data-capable** cable.

---

## Voltage drop on wires

Thin/long power wires have resistance. At 1.5 A, even small R means measurable voltage lost *before* the load.

**Mitigation:** shorter, thicker runs for 5 V servo power; star GND at USB breakout; don't daisy-chain power through a single Dupont jumper for all servos.

---

## Brownout

**Brownout** — supply voltage drops below what the MCU needs. ESP32 resets or behaves erratically. No graceful shutdown.

Feels like:
- Random reboot mid-animation
- "It works on USB from laptop but not from power bank"
- Worse when battery-powered USB packs sag

Fix the supply, not the code (usually).

---

## First power-up mindset

Before applying power:

1. **Visual inspect** — no obvious shorts, VCC/V+ not jumpered wrong
2. **Continuity** — multimeter beep: GND common across modules (power off!)
3. **Resistance** — no dead short between 5 V and GND (power off!)
4. **Strong supply** — bench 5 V / 2 A preferred over unknown port
5. **Servos unloaded** — horns free to move, not wedged against stops
6. **One subsystem at a time** if debugging — see [Ch. 08](08-tools-debugging-and-embedded-workflow.md)

Assembly checks: [wiring.md](../hardware/wiring.md).

---

## ESD and handling

Static discharge can kill sensitive chips. Touch grounded metal before handling ESP32. Don't slide modules on carpet. For a hobby desk build, basic awareness beats paranoia — but don't treat the C3-Zero like a rug skateboard.

---

## In Tiny Engineer — domain diagram

```mermaid
flowchart TB
  USB["USB 5V"]
  subgraph fiveV [5V domain]
    ESP5[ESP32 5V in]
    PCApwr[PCA9685 5V and V+]
    MAXvin[MAX98357A Vin]
    SERVOS[Servo motors]
  end
  subgraph threeV [3.3V logic domain]
    ESPcore[ESP32 GPIO and core]
    PCAlogic[PCA9685 VCC]
    OLED[OLED VCC]
  end
  USB --> fiveV
  ESP5 --> ESPcore
  ESPcore --> threeV
  PCApwr --> SERVOS
```

Bench bring-up with strong 5 V **before** cramming everything into the printed chest. Debugging power inside a closed shell is dark work.

---

**Next:** [Tools, debugging, and embedded workflow](08-tools-debugging-and-embedded-workflow.md)

**Reference:** [hardware/power.md](../hardware/power.md) · [hardware/wiring.md](../hardware/wiring.md)

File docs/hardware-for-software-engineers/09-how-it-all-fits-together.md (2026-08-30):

# How it all fits together

You've read the pieces. This chapter closes the loop on the guide's goal — **from software-only to hardware-capable** — then hands you to the build checklist. Tiny Engineer is the capstone: one system where electricity, firmware, buses, print, and motion connect. The vocabulary you picked up travels with you to the next board.

**Expect medium difficulty overall** — not an entry-level blinky kit, but a fair first hardware build for a software engineer who read the guide and benches before sealing the shell. Hardest areas for most SWEs: wiring density, servo mechanics, power under load. Easiest: REST and Wi-Fi once the bench work is solid.

---

## Three phases

```mermaid
flowchart TB
  subgraph learn [Learn phase]
    A[Electricity basics]
    B[MCU + buses]
    C[Print + mechanics]
  end

  subgraph build [Build phase]
    D[Print parts]
    E[Wire on bench]
    F[Flash firmware]
    G[Mechanical integration]
  end

  subgraph run [Run phase]
    H[Wi-Fi + web UI]
    I[REST API + agent hooks]
  end

  learn --> build --> run
```

**Learn** — this guide. Enough to not fry boards.

**Build** — [getting-started.md](../getting-started.md). Parts, print, wire, flash.

**Run** — Wi-Fi, `/anim`, Cursor hooks or your own integration.

You can overlap phases (print while reading, wire before all parts arrive). Don't skip **bench validation** before sealing the shell.

---

## The whole robot — one diagram

```mermaid
flowchart TB
  Agent["AI agent / curl / web UI"]
  Agent -->|HTTP Wi-Fi 2.4GHz| ESP["ESP32-C3-Zero"]

  subgraph power [Power from USB-C 5993]
    V5[5V rail]
    V33[3.3V logic via LDO]
  end

  ESP --> V5
  V5 --> V33

  ESP -->|I2C GP0/1| PCA["PCA9685 0x40"]
  ESP -->|I2C GP0/1| OLED["OLED 0x3C"]
  ESP -->|I2S GP2-4| AMP["MAX98357A"]
  AMP --> SPK[Speaker]

  V33 --> PCA
  V33 --> OLED
  V5 --> AMP
  PCA -->|V+ 5V PWM| SRV["5x HD-1370A servos"]

  PCA --> SRV

  subgraph mech [Printed mechanics Fusion to 3mf]
    BODY[Head Neck Hands Body]
  end

  SRV --> BODY
  ESP -.->|antenna keep-out| BODY
```

**Control plane:** Wi-Fi HTTP from your LAN.

**Data paths:** I2C for servos (via PCA9685) and display; I2S for audio.

**Power plane:** One 5 V in; 3.3 V logic derived; servos on 5 V motor rail.

**Mechanical plane:** Fusion CAD → printed parts → servos → pose.

---

## Subsystem → chapter map

| Subsystem | Learn in | Operate with |
| --- | --- | --- |
| Volts, amps, GND, two domains | Ch. 01, 07 | [power.md](../hardware/power.md) |
| ESP32-C3, GPIO, USB, antenna | Ch. 02 | [pinout.md](../hardware/pinout.md) |
| Wires, schematic reading | Ch. 03 | [wiring.md](../hardware/wiring.md), [diagram](../wiring/Tiny%20Engineer.drawio.png) |
| I2C, I2S, PWM | Ch. 04 | [interfaces.md](../hardware/interfaces.md) |
| Servos, horns, joints | Ch. 05 | [robot-movement.md](../robot-movement.md), [servos.md](../hardware/servos.md) |
| Print, PLA/PETG, Fusion | Ch. 06 | [3d_models/README.md](../../3d_models/README.md) |
| Supply sizing, brownout | Ch. 07 | [power.md](../hardware/power.md) |
| pio, serial, bisect debug | Ch. 08 | [testing.md](../hardware/testing.md) |
| HTTP API, agents | — (after hardware) | [api.md](../api.md), [integration.md](../integration.md), [hooks.md](../hooks.md) |

---

## Recommended build strategy (software brain edition)

### Phase A — Bench electronics (no shell)

1. Gather parts ([components.md](../hardware/components.md))
2. Wire on desk per [wiring.md](../hardware/wiring.md)
3. Flash firmware ([getting-started § Flash](../getting-started.md#4-flash))
4. Serial: PCA9685 OK
5. One servo moves via `/test/servo`
6. Wi-Fi setup, `/health`, web UI tests

**Why first:** when something fails, you can see wires and probe pins. A robot sealed in plastic is a black box.

### Phase B — Print and fit (parallel with A if possible)

1. Print structural parts ([3d_models](../../3d_models/README.md))
2. Test-fit servos in pockets — don't force
3. Adjust CAD if needed ([Fusion source](../../cad/TinyEngineer.f3d))

### Phase C — Mechanical integration

1. Mount servos with horns at center
2. Screw linkages, verify safe ranges ([robot-movement.md](../robot-movement.md))
3. Route wires, antenna clearance
4. Close shell — USB still reachable

### Phase D — Agent integration

Robot on Wi-Fi, animations work → [hooks.md](../hooks.md) or [integration.md](../integration.md).

**Temptation to avoid:** printing everything beautifully before verifying electronics. Pretty plastic won't fix a swapped SDA/SCL.

---

## Confidence milestones

Check these off — order matters:

| # | Milestone | How you know |
| --- | --- | --- |
| 1 | **Continuity sanity** | No short 5V–GND; GND common (meter, power off) |
| 2 | **Serial boot** | `pio device monitor` shows boot log, dim green LED |
| 3 | **PCA9685 detected** | Serial OK; missing = red LED hang |
| 4 | **One servo** | `/test/servo?index=0` moves head channel |
| 5 | **All five** | Each joint in safe range, no stall buzz |
| 6 | **Audio** | Sound on animation; if silent → `uploadfs` |
| 7 | **Wi-Fi stable** | `/health` over `tiny-engineer.local` or OLED IP |
| 8 | **Full anim** | e.g. `ring` — motion + sound, no reset |
| 9 | **In shell** | Same as 8 after mechanical assembly |
| 10 | **Agent** | Cursor hook or script triggers `/anim` |

Stuck on a milestone? Back one step, read [Ch. 08](08-tools-debugging-and-embedded-workflow.md) and [testing.md](../hardware/testing.md).

---

## What I'd tell any software engineer starting hardware

Not specific to day one on Tiny Engineer — things that stayed true across projects:

1. **Two voltages, one GND** — not optional mental model
2. **PCA9685 isn't optional** — plan I2C before servos
3. **Power is a feature** — 2 A supply saves hours of "random reboot" debugging
4. **Horns are calibration** — software clamps can't fix physical collision
5. **Bench before shell** — every time
6. **The docs split on purpose** — this guide for *why*, getting-started for *do*, hardware/ for *lookup*

The meta-lesson: hardware rewards the same curiosity that got you into software, but feedback is louder — smoke, buzz, heat. That's part of the fun.

---

## Handoff — go build

You're done with concepts when the milestones make sense and you know which doc to open for pin numbers.

**Operational checklist:** [getting-started.md](../getting-started.md)

**Parts → print → wire → flash → Wi-Fi → prove it → hooks.**

If you're mostly a software person: good. The bar isn't an EE degree — it's curiosity and willingness to probe a wire. In a world where AI spits out code in seconds, there's a particular joy in something on your desk that moves because *you* closed the loop from schematic to screw. Tiny Engineer is a fun capstone — but the bridge you built here works for the next project too.

---

**Next:** none — start building, or re-read any chapter from the [README](README.md).

**Reference:** [getting-started.md](../getting-started.md) · [hardware/README.md](../hardware/README.md) · [README.md](README.md)

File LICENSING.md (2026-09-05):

# Licensing

This repository contains both software and hardware design files. They are licensed separately.

## Software — MIT License

The following are licensed under the [MIT License](LICENSE):

| Path | Contents |
| --- | --- |
| `src/`, `include/`, `lib/`, `test/` | Firmware |
| `packages/`, `scripts/`, `package.json` | Integrations and tooling |
| `data/`, `assets/` | Firmware filesystem assets |
| `docs/` | Documentation (including wiring diagrams and hardware guides) |
| `.cursor/` | Cursor hook configuration |
| `platformio.ini`, `partitions.csv` | Build configuration |
| All other repository files | Unless explicitly listed under hardware below |

## Hardware designs — CERN-OHL-S-2.0

Mechanical CAD source and printable manufacturing outputs are licensed under the [CERN Open Hardware Licence Version 2 — Strongly Reciprocal (CERN-OHL-S-2.0)](3d_models/LICENSE):

| Path | Contents |
| --- | --- |
| `3d_models/cad/` | Source CAD (`.f3d`) |
| `3d_models/parts/` | Printable part exports (`.3mf`) |

Commercial use of these hardware designs is allowed. If you modify and distribute Products based on these designs, the reciprocal provisions of CERN-OHL-S-2.0 require that you make the corresponding Complete Source available under the same license. See [3d_models/LICENSE](3d_models/LICENSE) and [3d_models/NOTICE](3d_models/NOTICE) for copyright, warranty disclaimer, and Source Location details.

Documentation in `3d_models/README.md` is software documentation and remains under the MIT License.

### Source Location

Canonical hardware design source:

`https://github.com/jamro/tiny-engineer/tree/main/3d_models`

When distributing a specific revision, link to the corresponding tagged release or commit (for example, `https://github.com/jamro/tiny-engineer/tree/v0.1.0/3d_models`).

## Trademarks

The **Tiny Engineer** name and logo are **not** licensed under either MIT or CERN-OHL-S-2.0. See [TRADEMARK.md](TRADEMARK.md).

## Machine-readable license mapping

Per-path SPDX annotations are in [REUSE.toml](REUSE.toml).

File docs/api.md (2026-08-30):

# HTTP API

JSON HTTP server on the ESP32-C3. Source: [`src/http/http_server.cpp`](../src/http/http_server.cpp) and handlers under [`src/http/`](../src/http/), test routes in [`src/http/test_handlers.cpp`](../src/http/test_handlers.cpp).

Listens on **port 80** after STA Wi-Fi connects, or during setup AP mode at `http://192.168.4.1/`. Base URL is the board IP (OLED / serial) or `http://tiny-engineer.local` (mDNS, 2.4 GHz only).

Optional auth: when an `access_token` is configured in settings, all JSON API routes require `Authorization: Bearer <token>`. Empty token (default) means no auth. `GET /auth` is always public and reports whether auth is required. Missing/wrong token → **401** `{"ok":false,"error":"unauthorized"}`. HTML panel routes stay public (the UI prompts for the token). `Content-Type: application/json`. CORS: `Access-Control-Allow-Origin: *`, `Access-Control-Allow-Headers: Authorization`.

When WiFi credentials are not saved yet, control APIs (`/anim`, `/test/*`) return **503** `{"ok":false,"error":"wifi not configured"}`. Setup routes (`/`, `/config`, `/auth`, `/health`, `/settings`) stay available on the setup AP.

If boot WiFi credentials are missing, the device opens setup AP mode (`TinyEngineer-XXXX`) and serves the Config page. If saved credentials fail, it reopens setup AP mode. Hardware tests: [`docs/hardware/testing.md`](hardware/testing.md). How to wire this API into AI tools: [`integration.md`](integration.md).

Firmware answers mDNS A and AAAA (IPv6 link-local) so macOS does not wait 2–3s on a missing AAAA. If a client still pauses on the hostname, force IPv4 (`curl -4`). The IP on the OLED skips DNS entirely.

## Endpoints

### `GET /`

HTML endpoint index. Lists all routes plus supported parameters for `/anim`, `/settings`, and `/test/servo`. Safe, no hardware side effects. Always public (no Bearer required).

Open in a browser:

```bash
curl http://tiny-engineer.local/
```

Returns `Content-Type: text/html; charset=utf-8`.

### `GET /auth`

Whether API auth is required. Always public. Safe, no hardware side effects. Does not reveal the token.

```bash
curl http://tiny-engineer.local/auth
```

```json
{ "ok": true, "required": false, "wifi_configured": true, "provisioning": false }
```

| Field | Meaning |
| --- | --- |
| `ok` | Always `true` on this route |
| `required` | `true` when a non-empty access token is configured |
| `wifi_configured` | `true` when WiFi credentials are saved in NVS |
| `provisioning` | `true` when the setup AP is active |

### `GET /health`

Health. Safe, no hardware side effects. Uses live `WiFi.status()`, not the boot-time flag. Requires Bearer when auth is enabled.

```bash
curl http://tiny-engineer.local/health
curl -H "Authorization: Bearer YOUR_TOKEN" http://tiny-engineer.local/health
```

```json
{
  "ok": true,
  "uptime_ms": 12345,
  "free_heap": 120000,
  "heap_size": 320000,
  "cpu_temp_c": 41.2,
  "wifi": {
    "connected": true,
    "ip": "192.168.1.10",
    "rssi": -42,
    "hostname": "tiny-engineer.local"
  },
  "wifi_configured": true,
  "provisioning": false,
  "setup_ap_ssid": "",
  "setup_ap_ip": "",
  "oled": true
}
```

| Field | Meaning |
| --- | --- |
| `ok` | Always `true` on this route |
| `uptime_ms` | `millis()` since boot |
| `free_heap` | `ESP.getFreeHeap()` — bytes available for allocation |
| `heap_size` | `ESP.getHeapSize()` — total heap bytes; usage % = `(1 - free_heap / heap_size) × 100` |
| `cpu_temp_c` | ESP32-C3 on-die temperature in °C (not ambient); `null` if the sensor is unavailable |
| `wifi.connected` | `WiFi.status() == WL_CONNECTED` |
| `wifi.ip` | STA IPv4, or `""` if down |
| `wifi.rssi` | dBm, or `0` if down |
| `wifi.hostname` | mDNS name from settings (`{hostname}.local`, default `tiny-engineer.local`) |
| `wifi_configured` | `true` when WiFi credentials are saved in NVS |
| `provisioning` | `true` when setup AP mode is active |
| `setup_ap_ssid` | Setup AP SSID when `provisioning` is true, else `""` |
| `setup_ap_ip` | Setup AP IP when `provisioning` is true (usually `192.168.4.1`), else `""` |
| `oled` | SSD1306 probed and initialized |

### `GET /settings`

Persistent settings from NVS. Safe, no hardware side effects. Developer guide for adding settings: [`settings.md`](settings.md).

```bash
curl http://tiny-engineer.local/settings
```

```json
{
  "ok": true,
  "sleep_timeout": 10,
  "hostname": "tiny-engineer",
  "volume": 70,
  "welcome": true,
  "serial_log": false,
  "continuous_timeout": 5,
  "loading": "progress",
  "access_token_set": false,
  "wifi_configured": true,
  "wifi_ssid": "MyNetwork",
  "wifi_password_set": true
}
```

| Field | Meaning |
| --- | --- |
| `sleep_timeout` | Minutes of continuous animation `none` before OLED blanks (default **10**). Any non-idle animation keeps the device awake and restarts the idle clock when returning to `none`. Other APIs do not affect the timer. |
| `hostname` | DHCP/mDNS label without `.local` (default **`tiny-engineer`**) |
| `volume` | Speaker gain percent for tones and WAV playback (default **70**) |
| `welcome` | Play welcome animation on boot when Wi-Fi connects (default **true**). Also enables head/neck motion during `sleep_inertia` loading |
| `serial_log` | USB serial debug logging (default **false**). When off, diagnostic `Serial` output is suppressed |
| `continuous_timeout` | Minutes a continuous animation (`typing` / `reading` / `thinking`) may run before the firmware switches to `attention` then idle (default **5**) |
| `loading` | Boot loading screen: `progress` (bar + large IP for 3 s) or `sleep_inertia` (eyes wake; no bar/IP). Default **`progress`**. Applies on **next reboot** |
| `access_token_set` | `true` when a non-empty access token is stored (secret itself is never returned) |
| `wifi_configured` | `true` when a WiFi SSID is saved |
| `wifi_ssid` | Saved network name (password is never returned) |
| `wifi_password_set` | `true` when a non-empty WiFi password is saved |

### `POST /settings`

Update one or more settings. Query params. Values are written to NVS. `sleep_timeout`, `volume`, `welcome`, `serial_log`, `continuous_timeout`, and `access_token` apply immediately; a changed `hostname` or `loading` takes effect on the **next reboot**. WiFi credentials (`wifi_ssid` + `wifi_password`) are accepted **only in setup AP mode**; they are **tested before save**; on success the device connects to the home network and returns `wifi_connect_success`, `wifi_ip`, and `wifi_hostname`. Outside setup AP → **400** `wifi setup only in AP mode`. Requires Bearer when auth is enabled.

```bash
curl -X POST "http://tiny-engineer.local/settings?sleep_timeout=2"
curl -X POST "http://tiny-engineer.local/settings?hostname=desk-bot"
curl -X POST "http://tiny-engineer.local/settings?volume=40"
curl -X POST "http://tiny-engineer.local/settings?welcome=0"
curl -X POST "http://tiny-engineer.local/settings?serial_log=1"
curl -X POST "http://tiny-engineer.local/settings?continuous_timeout=10"
curl -X POST "http://tiny-engineer.local/settings?loading=sleep_inertia"
curl -X POST "http://tiny-engineer.local/settings?access_token=secret"
curl -X POST "http://tiny-engineer.local/settings?access_token="
curl -X POST "http://192.168.4.1/settings?wifi_ssid=MyNetwork&wifi_password=secret"
curl -X POST "http://tiny-engineer.local/settings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"
```

```json
{
  "ok": true,
  "sleep_timeout": 1,
  "hostname": "desk-bot",
  "volume": 70,
  "welcome": true,
  "serial_log": false,
  "continuous_timeout": 5,
  "loading": "progress",
  "access_token_set": true,
  "wifi_configured": true,
  "wifi_ssid": "MyNetwork",
  "wifi_password_set": true,
  "wifi_connect_success": true,
  "wifi_ip": "192.168.1.10",
  "wifi_hostname": "tiny-engineer.local",
  "reboot_required": true
}
```

| Param | Type | Range |
| --- | --- | --- |
| `sleep_timeout` | integer | 1–1440 minutes (positive) |
| `hostname` | string | 1–31 chars, `[A-Za-z0-9-]`, not starting/ending with `-` |
| `volume` | integer | 0–100 percent |
| `welcome` | integer | `0` or `1` (boot welcome animation) |
| `serial_log` | integer | `0` or `1` (USB serial debug logging) |
| `continuous_timeout` | integer | 1–1440 minutes (positive) |
| `loading` | string | `progress` or `sleep_inertia` |
| `access_token` | string | 0–64 printable ASCII; empty string clears the token and disables auth |
| `wifi_ssid` | string | 1–32 chars; setup AP only; must be sent with `wifi_password` |
| `wifi_password` | string | 0–63 chars; setup AP only; empty allowed for open networks; tested before save |

At least one param required. Invalid or missing-all → **400**. WiFi params outside setup AP → **400** `wifi setup only in AP mode`. WiFi test failure → **400** with error such as `SSID not found`, `Auth failed`, or `Timeout`. `reboot_required` is present and `true` only when the saved hostname differs from the one used at this boot. After successful WiFi save, `wifi_connect_success`, `wifi_ip`, and `wifi_hostname` are included.

### `POST /settings/reset`

Factory reset: clears the NVS `te` namespace and restores all settings to compile-time defaults, including WiFi credentials. After reset, power-cycle (or press reset) so the device reopens setup AP mode and WiFi can be configured again. Until reboot, credentials are cleared in NVS but the radio may still be on the previous STA network. No query params. Requires Bearer when auth is enabled. Same JSON shape as `GET /settings`; includes `reboot_required` when the boot hostname, loading screen, or saved WiFi differed from defaults before reset.

The Config web UI clears the browser-stored Bearer token and shows a one-shot gate: power-cycle the device, then join the robot WiFi shown on the OLED and open the setup page. It does not poll for reconnect.

```bash
curl -X POST "http://tiny-engineer.local/settings/reset"
```

```json
{
  "ok": true,
  "sleep_timeout": 10,
  "hostname": "tiny-engineer",
  "volume": 70,
  "welcome": true,
  "serial_log": false,
  "continuous_timeout": 5,
  "loading": "progress",
  "access_token_set": false,
  "reboot_required": true
}
```

NVS write failure → **400** `{"ok":false,"error":"factory reset failed"}`.

### `POST /test/audio`

Plays 500 / 700 / 1000 Hz on the MAX98357A (`runSoundTest()`).

```bash
curl -X POST http://tiny-engineer.local/test/audio
```

```json
{ "ok": true, "test": "audio" }
```

### `POST /test/audio/bell`

Plays `assets/bell.wav` (44100 Hz mono PCM) from LittleFS (`playBell()`). First flash or after changing `data/bell.wav`, upload the filesystem:

```bash
pio run -t uploadfs
```

```bash
curl -X POST http://tiny-engineer.local/test/audio/bell
```

```json
{ "ok": true, "test": "bell" }
```

If the WAV is missing or unreadable, returns **500** with `{"ok":false,"error":"bell playback failed"}`.

### `POST /test/screen`

OLED demo: title, `HELLO`, X in a box (`runOledTest()`). No-op if the panel is missing.

```bash
curl -X POST http://tiny-engineer.local/test/screen
```

```json
{ "ok": true, "test": "screen" }
```

### `POST /test/movement`

All five servos: 90° → 105° → 75° → 90° (`runServoTest()`). Needs a strong 5 V supply — see [power.md](hardware/power.md).

```bash
curl -X POST http://tiny-engineer.local/test/movement
```

```json
{ "ok": true, "test": "movement" }
```

### `POST /test/led`

Onboard WS2812 on GPIO10: R → G → B → white → off (`runRgbTest()`), then fades back to the current animation color (see [RGB LED](#rgb-led)).

```bash
curl -X POST http://tiny-engineer.local/test/led
```

```json
{ "ok": true, "test": "led" }
```

### `POST /test/servo`

Smoothly move one servo to an angle at **~40°/s** (`SERVO_SPEED_DEG_S`) from its last commanded position. Query params required. Handler blocks until the move finishes.

| Param | Type | Range |
| --- | --- | --- |
| `index` | integer | `0`–`4` |
| `angle` | number | `0`–`180` |

```bash
curl -X POST "http://tiny-engineer.local/test/servo?index=0&angle=90"
```

```json
{ "ok": true, "test": "servo", "index": 0, "angle": 90 }
```

Wrong params return **400** and do not move any servo:

| `error` | When |
| --- | --- |
| `missing index or angle` | Either query param absent |
| `invalid index` | Non-integer `index` (e.g. `abc`, `1x`) |
| `index out of range` | `index` outside `0`–`4` |
| `invalid angle` | Non-numeric `angle` |
| `angle out of range` | `angle` outside `0`–`180` |

Assembled robot: prefer the safe band in [servos.md](hardware/servos.md); this route allows full electrical travel for bench bring-up.

### `GET /anim`

Current animation name. Default at boot: `none`. No hardware side effects.

```bash
curl http://tiny-engineer.local/anim
```

```json
{ "ok": true, "animation": "none" }
```

| Field | Meaning |
| --- | --- |
| `animation` | `none`, `typing`, `reading`, `thinking`, `ring`, `welcome`, `attention`, `error`, `abort`, `dead`, `wakeup`, or `sleep` |

### `POST /anim`

Request an animation switch. Each animation runs at least **1s**; if the current one is shorter than that, the switch waits until the hold ends. Rapid posts during the hold keep only the **latest** request. Response `animation` is the currently playing name (may still be the old one until the hold ends). Hand moves use speed-limited servo wrappers.

| Param | Type | Values |
| --- | --- | --- |
| `name` | string | `none`, `typing`, `reading`, `thinking`, `ring`, `welcome`, `attention`, `error`, `abort`, `dead`, `wakeup`, `sleep` |

```bash
curl -X POST "http://tiny-engineer.local/anim?name=typing"
curl -X POST "http://tiny-engineer.local/anim?name=reading"
curl -X POST "http://tiny-engineer.local/anim?name=thinking"
curl -X POST "http://tiny-engineer.local/anim?name=ring"
curl -X POST "http://tiny-engineer.local/anim?name=welcome"
curl -X POST "http://tiny-engineer.local/anim?name=wakeup"
curl -X POST "http://tiny-engineer.local/anim?name=sleep"
curl -X POST "http://tiny-engineer.local/anim?name=attention"
curl -X POST "http://tiny-engineer.local/anim?name=error"
curl -X POST "http://tiny-engineer.local/anim?name=abort"
curl -X POST "http://tiny-engineer.local/anim?name=dead"
curl -X POST "http://tiny-engineer.local/anim?name=none"
```

```json
{ "ok": true, "animation": "typing" }
```

| `name` | Behavior |
| --- | --- |
| `none` | Head/neck/body → mid; hands down (right `min`, left `max` — inverted scales), then hold |
| `typing` | **Continuous.** Alternating hands with randomness (15° band from hand limits). Head nods slowly on lowest 10° of head limits. Body sways ±5° around mid; neck counters opposite so head stays put. Runs until replaced, or until `continuous_timeout` triggers `attention`. Same-name re-`POST` refreshes that timeout without restarting motion. |
| `reading` | **Continuous.** Hands/body park as in `none`. Head nods on same lowest 10° band as typing, but slower. Neck sweeps ±10° around mid; right (angle down) slower than left (angle up). Occasional right-hand down-arrow bursts (1–3 presses, same 15° band as typing). Runs until replaced, or until `continuous_timeout` triggers `attention`. Same-name re-`POST` refreshes that timeout without restarting motion. |
| `thinking` | **Continuous.** Hands/body park as in `none`. Head (pitch) and neck (yaw) ease from the current pose into thinking poses (up + slight left/right). Move → pause → optional micro-adjust (sometimes chained) → pause; nearby pose drift with occasional larger shifts after ~2.2 s, more often over time. Axes stagger start/duration; no periodic sway. Runs until replaced, or until `continuous_timeout` triggers `attention`. Same-name re-`POST` refreshes that timeout without restarting motion. |
| `ring` | **One-shot** service-bell gesture; does not loop. Wind-up (body `min`, neck mid, head mid+10°, both hands `max`) → fast right-hand strike to `min+5°` with head to `min` → plays `bell.wav` once on strike (LittleFS; same `uploadfs` requirement as `/test/audio/bell`) → slower bounce to `min+20°` → return to `none` pose and stop. After completion, `GET /anim` reports `none`. |
| `welcome` | **One-shot** hello gesture synced to `welcome.wav` (~2.7 s). Right hand raises during "Hello, human.", holds through the pause, wiggles during "What are we building today?", then lowers. Head nods to mid+10° and returns. Plays automatically after successful Wi-Fi connect at boot; also via API. Requires `welcome.wav` on LittleFS (same `uploadfs` flow as `bell.wav`). After completion, `GET /anim` reports `none`. |
| `attention` | Friendly input-request gesture synced to `attention.wav` (~3.0 s, "pst... human.... you might want to take a look"). Moves into a calm prompt pose first (centered body/neck, head slightly up, right hand raised partway), waits until all servos stop, then plays audio with phased eye cues and light neck/head/hand motion during playback (whisper hold → lean toward user → glance/point on "take a look"). After audio ends (or if audio fails to start), holds a gentle waiting loop for **1 minute** (soft head/neck drifts plus occasional slight right-hand waves), then returns to `none`. Requires `attention.wav` on LittleFS (same `uploadfs` flow as `bell.wav`). |
| `error` | Critical task-obstacle gesture synced to `error.wav` (~2.2 s, "Uh-oh. Human, we have a problem."). Moves into an obstacle-presenting pose first (body/neck angled toward the task, head concerned/down, right hand presenting the blocker, left hand indicating task area), waits until the pose settles, then plays audio with small nervous head/neck glances during playback. After audio ends (or if audio fails to start), holds a subtle blocked loop for **1 minute**, then returns to `none`. Requires `error.wav` on LittleFS (same `uploadfs` flow as `bell.wav`). |
| `abort` | **One-shot** resigned abort gesture synced to `abort.wav` (~2.5 s, "Fine. I didn't want to finish it anyway."). Raises both hands, lifts the head, and twists the neck sideways before audio starts. During playback it shrugs, dips the head, and adds a dismissive side twist with matching eye glances/squints. Requires `abort.wav` on LittleFS (same `uploadfs` flow as `bell.wav`). After completion, returns to `none` pose and `GET /anim` reports `none`. |
| `dead` | **Hold.** Out-of-power: same obstacle pose + `error.wav` as `error` ("Uh-oh. Human, we have a problem."), but eyes use a failing-display flicker (irregular heights + brief blank pulses, denser near the end) instead of the error nervous scan. When the line ends (or audio fails), eyes squeeze nearly shut (~300 ms) while head/hands collapse, hold shut briefly (~200 ms), then snap to **X X**. Stays in that pose with X eyes and pulsing red until another animation is requested. Does not auto-return to `none`. Requires `error.wav` on LittleFS. |
| `wakeup` | **One-shot** sleep-inertia wake (~5.5 s + settle), same sequence as boot `loading=sleep_inertia`. Eyes open over 2 s (cubic ease) from closed, two blinks at 2.4 s and 3.8 s, head rises from chin-down with a fading neck wave. Always moves head/neck/hands (API path). After completion, `GET /anim` reports `none`. Does not play welcome audio — use `welcome` for that. |
| `sleep` | **One-shot** enter sleep: eye close + head lowers to chin-down (`SLEEP_HEAD_DOWN`, same pose `wakeup` starts from), then blank OLED and `DISPLAYOFF`. Same path as the idle `sleep_timeout`. Holds `sleep` until the head settles; then `GET /anim` reports `none` while the device stays asleep until another non-`sleep`/`none` animation wakes it. |

Wrong params return **400**:

| `error` | When |
| --- | --- |
| `missing name` | Query param `name` absent |
| `unknown animation` | `name` not `none`, `typing`, `reading`, `thinking`, `ring`, `welcome`, `attention`, `error`, `abort`, `dead`, `wakeup`, or `sleep` |

## Errors

| Status | Body | When |
| --- | --- | --- |
| `400` | `{"ok":false,"error":"..."}` | Bad `/test/servo` or `/anim` params (see tables above) |
| `401` | `{"ok":false,"error":"unauthorized"}` | Access token configured and `Authorization: Bearer` missing or wrong |
| `404` | `{"ok":false,"error":"not found"}` | Unknown path |
| `405` | `{"ok":false,"error":"method not allowed"}` | Wrong method on a `/test/*`, `/settings`, `/settings/reset`, `/anim`, or `/auth` path |

Test routes are **POST**. GET/prefetch would move hardware. `/anim` allows **GET** (read) and **POST** (set). `/auth` is **GET** only and always public.

## Behaviour

Test handlers **block** until the test finishes. The client waits. After each test, OLED returns to `ROBOT READY` plus IP (or `WIFI FAIL`).

`/anim` responses return immediately; typing motion runs in the main loop via non-blocking servo updates. Animation switches may defer up to 1s so the active animation holds its minimum duration; only the latest pending request is applied. Continuous animations (`typing`, `reading`, `thinking`) that stay active longer than `continuous_timeout` minutes switch to `attention`, which holds ~1 minute then finishes to `none`. Re-`POST`ing the same continuous animation (e.g. `typing` while already `typing`) does not restart motion, but resets the continuous-timeout clock.

The onboard RGB LED follows the active animation (see [RGB LED](#rgb-led)).

One request at a time — the Arduino `WebServer` is single-threaded.

## RGB LED

Onboard WS2812 on **GPIO10** (`RGB_LED_PIN`). Animation-driven colors are handled in [`src/hardware/rgb.cpp`](../src/hardware/rgb.cpp) and switch when `POST /anim` applies a new state (same 1s minimum hold as servos/eyes).

| Animation | LED color |
| --- | --- |
| `typing`, `reading`, `thinking`, `welcome`, `ring`, `wakeup` | White (full intensity) |
| `attention`, `error`, `dead` | Red pulse: 500 ms 10%→100%, 500 ms hold 100%, 500 ms 100%→10%, repeat |
| `abort` | Red (full intensity, solid) |
| `none`, `sleep` | Off |

Transitions take **1 s** with smooth fade in/out (pulse modes start immediately, no enter fade):

- **Off ↔ color** — single 1 s fade (e.g. idle → typing fades in white; ring → `none` fades out).
- **White ↔ solid red** — fade out to black (500 ms), then fade in to the new color (500 ms).
- **Leaving pulse** — 1 s fade from the current pulse brightness to the new target.

Switching between animations that share the same color (e.g. `typing` → `reading`) does not restart a fade.

Boot uses dim green `(0, 32, 0)` as a status indicator during init. After `ROBOT READY`, the LED fades to white if `welcome` runs (Wi-Fi OK) or off if idle. Fatal PCA9685 / I2S errors set solid dim red and hang — not animation-driven.

`POST /test/led` runs a hardware colour cycle and then restores the current animation LED state.

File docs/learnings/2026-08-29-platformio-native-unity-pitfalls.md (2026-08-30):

# PlatformIO native Unity env pitfalls

Session learnings from adding `test/test_native/` (20 tests) as a host-side
Unity env on 2026-08-29.

## Unity 2.x API

- PlatformIO `test_framework = unity` pulls Unity 2.6.1. Assertions are
  `TEST_ASSERT_*` (`TEST_ASSERT_EQUAL`, `TEST_ASSERT_TRUE`,
  `TEST_ASSERT_EQUAL_FLOAT`). The older two-argument `TEST_ASSERT(condition,
  message)` form does not exist in this version.
- `TEST_ASSERT_FLOAT` is not an assertion in Unity 2.x; use
  `TEST_ASSERT_EQUAL_FLOAT(expected, actual)`.

## One program per test dir

- All files in a test dir link into a single host binary, so exactly one
  `main()` per dir. `test_main.cpp` declares the suites (`extern
  void test_*(void)`) and runs them via `RUN_TEST`.
- Suite files define plain `void test_...` functions; no per-file main.

## test_build_src = off

- `[env:native]` sets `test_build_src = off`: src/ is not compiled as a build
  target. Tests `#include` the pure, Arduino-free module `.cpp` directly
  (e.g. `#include "settings.cpp"`), pulling the code under test into the test
  binary without the Arduino HAL.
- Works only for host-compilable modules (no Arduino.h, no ESP32 HAL).
  Hardware-facing code stays covered by firmware build + boot capture.

## Bare `pio run` gotcha

- A bare `pio run` targets every env in platformio.ini, including the native
  test env, which tries to compile src/ for the host and fails on
  Arduino includes (verified 2026-08-29). Always pass explicit envs:
  `pio run -e esp32-c3-devkitm-1 -e esp32dev`.
- Also documented in the platformio.ini header.

## Inherited `[env]` keys

- Common-section keys (`platform`, `framework`, `lib_deps`,
  `board_build.partitions`, `extra_scripts`) are inherited by `[env:native]`
  and must be cleared or overridden (`framework =`, `lib_deps =`,
  `extra_scripts =`), or the host build tries to fetch ESP32 packages.

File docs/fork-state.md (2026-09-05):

# Fork state

This repository is a satware AG fork of [jamro/tiny-engineer](https://github.com/jamro/tiny-engineer).

| Property | Value |
|---|---|
| Role | Fork development line: upstream `main` + satware work (multi-arch port, native tests, CI) |
| Upstream position | Never behind `jamro/main` (drift gate); ahead commits are fork work |
| Protection | Ruleset `protect-main` on `main` (no deletion, no force push) |
| Sync trigger | New upstream push - re-audit the new commits, then merge into `main` (no ff once diverged) |

## Verdict (2026-08-29, updated 2026-09-05)

Single-author hobby project, clean MIT license, no commercial strings.
The 2026-08-29 exact-mirror state ended when PR #1 squash-merged to
`main` (`071cef1`, 2026-08-30): `main` now carries the fork's own work
and the standing invariant is "not behind upstream" - ahead commits are
the fork's development, not drift.

2026-08-30: upstream pushed 4 commits mid-day (dead/wakeup/sleep
animations, BOM speaker link, hardware-for-software-engineers guide;
+2404/-150). Re-audit: all animation/docs work, no license or policy
change. Merged into `main` at `56037f3`, no conflicts (single
auto-merged file: `src/hardware/rgb.cpp`).

2026-09-05: upstream pushed 1 commit (`aaaa420`, desk pad screw hole
fix). Re-audit: mechanical CAD fix plus a licensing reorg - software
stays MIT (scope clarified in `LICENSING.md`); `3d_models/cad/` and
`3d_models/parts/` are now CERN-OHL-S-2.0 (commercial use allowed,
reciprocal on modified distributed products); the Tiny Engineer
name/logo are trademark-reserved and not licensed (`TRADEMARK.md`,
`REUSE.toml`). No restriction on the fork's development line: all
ahead commits are firmware/CI/docs (MIT scope), and factual references
(fork repo name, README attribution) stay within the permitted uses.
Merged into `main` at `11c9577`, no conflicts. Finding: upstream
committed `3d_models/.DS_Store` (macOS junk).

The full provenance audit of the project and its creator (2026-08-29) is
kept internal; only this non-personal fork state is tracked here.

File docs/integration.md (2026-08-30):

# Integrating Tiny Engineer

Tiny Engineer is a Wi-Fi desk robot. Drive it from any tool that can make HTTP requests, or use the Cursor-specific helper that maps agent hook events to poses.

Robot must be on the same network. Base URL: `http://tiny-engineer.local` (or the IP shown on the OLED). Full HTTP reference: [`api.md`](api.md).

Two integration paths:

| Path | Best for | How |
|---|---|---|
| **REST API** | Any AI IDE, script, CI, custom agent | `POST /anim?name=…` |
| **Cursor CLI** | Cursor project hooks | `npx` → `tiny-engineer-cursor` |

```mermaid
flowchart TB
  subgraph anyIde [Any AI IDE or script]
    HookOrScript[Agent event or your code]
    HookOrScript --> Post["POST /anim?name=typing|reading|…"]
  end
  subgraph cursorPath [Cursor]
    CursorHook[Cursor hooks.json]
    CursorHook --> Npx["npx tiny-engineer-cursor"]
    Npx --> Post
  end
  Post --> Robot[Tiny Engineer on Wi-Fi]
```

---

## 1. REST API (any AI IDE)

Call the board directly. Works with Claude Code, Windsurf, Continue, custom plugins, shell hooks, or anything that can `POST` over HTTP.

### Main call

```bash
curl -X POST "http://tiny-engineer.local/anim?name=typing"
```

| `name` | Typical use |
|---|---|
| `typing` | Agent writing / editing / running tools |
| `reading` | Agent reading files / context |
| `thinking` | Agent reasoning / waiting on a long step |
| `ring` | Turn finished (attention ping) |
| `welcome` | Session start / greeting |
| `wakeup` | Sleep-inertia wake (eyes/head) |
| `sleep` | Force sleep (eye close + OLED off) |
| `attention` | Needs user input |
| `error` / `abort` | Failure / cancel |
| `dead` | Out of power (error line, then X X hold) |
| `none` | Idle / clear pose |

Firmware holds each pose ≥1s and keeps only the **latest** pending switch — spam-safe. Auth is optional: if you set an access token on the device, send `Authorization: Bearer <token>` (check `GET /auth` for `required`). Prefer short timeouts (e.g. 2s) and ignore network errors so the agent never stalls if the robot is offline.

### Minimal examples

**Shell**

```bash
curl -4 -sS -m 2 -X POST "http://tiny-engineer.local/anim?name=reading" >/dev/null || true
```

**JavaScript (Node 18+)**

```js
await fetch("http://tiny-engineer.local/anim?name=thinking", {
  method: "POST",
  signal: AbortSignal.timeout(2000),
}).catch(() => {});
```

**Python**

```python
import urllib.request
urllib.request.urlopen(
    urllib.request.Request(
        "http://tiny-engineer.local/anim?name=typing",
        method="POST",
    ),
    timeout=2,
)
```

Wire these into your IDE’s hook / plugin / lifecycle events (prompt submitted → `reading`, tool use → `typing`, turn end → `ring`, etc.). Mapping is yours; the robot only cares about `name`.

Health check (no motion):

```bash
curl http://tiny-engineer.local/health
```

More routes (tests, servo, web UI): [`api.md`](api.md).

---

## 2. Cursor dedicated script

For [Cursor](https://cursor.com/) only: a small Node CLI reads Cursor hook JSON on stdin, picks an animation, and POSTs `/anim`. No need to implement the event map yourself.

### Command

```bash
npx -y --package=https://github.com/jamro/tiny-engineer/archive/refs/heads/main.tar.gz tiny-engineer-cursor
```

- HTTPS **tarball** (not `github:…` SSH shorthand — that often fails in Cursor hooks with no SSH agent).
- Bin name `tiny-engineer-cursor` required after `--package=…`.
- Optional: `--url http://192.168.x.x` (default `http://tiny-engineer.local`).
- Auth: if the device has an `access_token`, set `TINY_ENGINEER_TOKEN` in the process env or a project-root `.env` file (same value). The CLI sends `Authorization: Bearer …`. No token → no header (auth disabled on device).
- `--help` for usage and event map.

### Smoke test

```bash
npx -y --package=https://github.com/jamro/tiny-engineer/archive/refs/heads/main.tar.gz tiny-engineer-cursor --help
echo '{"hook_event_name":"stop"}' | npx -y --package=https://github.com/jamro/tiny-engineer/archive/refs/heads/main.tar.gz tiny-engineer-cursor
```

### Wire into any Cursor project

In that project’s `.cursor/hooks.json`, use the same command for each anim hook. Set **`timeout` ≥ 30** (cold `npx` can exceed 2s). Full sample + event table: [`hooks.md`](hooks.md).

Inside this firmware repo you can instead run the local bin while developing the CLI:

```bash
node packages/tiny-engineer-cursor/bin/tiny-engineer-cursor.js
```

---

## Which to choose?

- **Building for one IDE / custom agent** → REST. One `POST`, zero Node dependency.
- **Using Cursor and want zero mapping code** → Cursor CLI + hooks.
- **Both** are fine together: CLI is just a thin client of the same `/anim` API.

Prerequisites for either path: flash firmware, join 2.4 GHz Wi-Fi, confirm `http://tiny-engineer.local/health` (or the OLED IP) responds.

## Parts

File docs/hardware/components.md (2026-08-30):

# Hardware inventory

Selected hardware only. Do not substitute parts from this list without updating this file, [pinout.md](pinout.md), and [wiring.md](wiring.md).

Constants cited below match [`include/pins.h`](../../include/pins.h).

## Product links

| Part | Link |
| --- | --- |
| Waveshare ESP32-C3-Zero | https://docs.waveshare.com/ESP32-C3-Zero |
| Adafruit PCA9685 16-channel PWM servo driver | https://www.adafruit.com/product/815 |
| PowerHD HD-1370A | https://www.chd.hk/Product_Detail.aspx?id=30 |
| MAX98357A I2S class-D mono amplifier | https://www.aliexpress.us/item/3256805196806369.html |
| 8 Ω / 1 W mono speaker | https://www.aliexpress.us/item/3256807341987395.html |
| 0.91" 128×32 OLED (SSD1306, I2C) | https://www.raystar-optronics.com/oled-graphic-display-module/oled-i2c-ssd1306.html |
| Adafruit 5993 USB-C breakout | https://www.adafruit.com/product/5993 |

## Waveshare ESP32-C3-Zero

| Field | Value |
| --- | --- |
| Exact model | Waveshare ESP32-C3-Zero (ESP32-C3FH4) |
| Quantity | 1 |
| Purpose | Main controller: I2C, I2S, USB CDC, Wi-Fi, onboard RGB |
| Operating voltage | GPIO **3.3 V**. External power on the **5V** pad: 3.7–6 V (robot uses the +5V rail) |
| Logic | **3.3 V only** — do not drive 5 V into GPIO |
| Radio | Wi-Fi 2.4 GHz (product use). BLE present on silicon but **out of scope** |
| USB | Native USB on GPIO18/19 — reached via Adafruit 5993 D+/D− (onboard USB-C unused when assembled) |
| Flash | 4 MB stacked flash on GPIO12–GPIO17 (those GPIOs are **not exposed**) |
| Onboard RGB | WS2812 on **GPIO10** |
| Firmware notes | Boot: dim green status. Animations: white (typing/reading/thinking/welcome/ring/wakeup), pulsing red (attention/error/dead), solid red (abort), off (idle/sleep). 1 s fade between non-pulse states. Fatal init errors: solid dim red + hang. See [`docs/api.md`](../../api.md#rgb-led) |
| BOOT | Button / strapping on **GPIO9** |
| RESET | Separate RESET button (CHIP_EN), not a GPIO |
| UART0 silkscreen | TX = GPIO21, RX = GPIO20 |
| USB D− / D+ | GPIO18 / GPIO19 (native USB) |
| 3V3 regulator | Onboard LDO (Waveshare: ME6217C33M5G). For **logic loads only** |
| Important pins | See [pinout.md](pinout.md) |
| Limits | Do not power servos from **3V3**. Do not cover the ceramic antenna with metal, PCB, or plastic. |
| Firmware note | PlatformIO `board = esp32-c3-devkitm-1` is a **build target**, not the physical module. Physical board is C3-Zero. |

## Adafruit PCA9685 16-channel PWM servo driver

| Field | Value |
| --- | --- |
| Exact model | Adafruit 16-Channel 12-bit PWM/Servo Driver (PCA9685) |
| Quantity | 1 |
| Purpose | Independent 50 Hz servo PWM so ESP32 timing is not the PWM source |
| Operating voltage | **VCC** (logic): 3.3 V from ESP32 **3V3**. **V+** (servos): +5V rail |
| Interface | I2C |
| Address | `0x40` (`PCA9685_ADDRESS` in firmware). A0–A5 pads can change this |
| PWM | 12-bit, firmware `setPWMFreq(50)` |
| Important pins | As drawn: **5V** (servo-rail in), **V+** (to servo 5V), **VCC** (3V3 logic), **GND**, **SDA**, **SCL**, **PWM**. OE not drawn |
| Channels used | 0–4 (five servos). 5–15 unused |
| Limits | **V+** and **VCC** must stay separate. Do not jumper servo power onto logic VCC on this robot |
| Firmware note | Detection at `0x40` is a **hard fail** in the bring-up test |

## PowerHD HD-1370A

| Field | Value |
| --- | --- |
| Exact model | PowerHD HD-1370A analog micro servo |
| Quantity | 5 |
| Purpose | Robot joints (Head / Neck / L hand / R hand / Body — [robot-movement.md](../robot-movement.md)) |
| Operating voltage | 4.8–6.0 V (robot: **+5V** via PCA9685 **V+**) |
| Interface | Analog PWM, ~50 Hz. Signal is 3.3 V from PCA9685 — acceptable for this servo class |
| Pulse | Neutral ~1500 µs. Declared range ~**800–2200 µs** (`SERVO_MIN_US` / `SERVO_MAX_US`) |
| Current (datasheet stall) | ~260 mA @ 4.8 V, ~320 mA @ 6.0 V |
| No-load current | ~110 mA @ 4.8 V, ~120 mA @ 6.0 V |
| Idle current | ~4 mA @ 4.8 V, ~5 mA @ 6.0 V |
| Torque / speed | 0.4 kg·cm / 0.12 s/60° @ 4.8 V; 0.6 kg·cm / 0.10 s/60° @ 6.0 V |
| Size / mass | ~20.2 × 8.5 × 17.6 mm, ~3.7 g |
| Important pins | SIG, +5V, GND (JR-style 3-wire) |
| Limits | Manufacturer sheet also lists **~130°** travel over 800–2200 µs, while many retailers say 0–180°. Treat 0–180° as **nominal**, not a mechanical guarantee. |

> [!WARNING]
> Never power the servos from the ESP32 3.3 V regulator.

Firmware uses **per-servo safe ranges** in [`include/servos.h`](../../include/servos.h) (`SERVO_SPECS`). Tune after assembly if needed. Do not command full 0–180° / 800–2200 µs on the assembled robot. See [servos.md](servos.md).

## MAX98357A I2S class-D mono amplifier

| Field | Value |
| --- | --- |
| Exact model | MAX98357A breakout (I2S in, speaker out) |
| Quantity | 1 |
| Purpose | Digital audio → mono speaker. ESP32 never drives the speaker as GPIO PWM |
| Operating voltage | **Vin** 2.5–5.5 V. Drawing: USB **5V** → **Vin** |
| I2S logic | 3.3 V from ESP32 (compatible) |
| Interface | I2S: **BCLK**, **WS/LRC**, **DIN**. No MCLK |
| Sample rates | Chip: 8–96 kHz. Firmware: **44100 Hz**, 16-bit, stereo slot mode |
| Output power (typical) | ~1.8 W into 8 Ω @ 5 V / 10% THD (datasheet-class figure) |
| Important pins | Drawn: **Vin**, **GND**, **BCLK**, **LRC**, **DIN**. **SPK+** / **SPK-** not drawn. **GAIN** / **SD** not wired (breakout defaults: GAIN floating ≈ 9 dB, SD pulled up ≈ left channel) |
| Limits | Output is **BTL**. Do not connect SPK- to GND. Do not feed SPK+/SPK- into another amplifier. Do not drive the speaker from ESP32 GPIO |

> [!WARNING]
> MAX98357A SPK- is not ground.

## Speaker

| Field | Value |
| --- | --- |
| Exact model | 8 Ω / 1 W mono speaker (AliExpress listing above) |
| Quantity | 1 |
| Purpose | Acoustic output |
| Operating voltage | Not a voltage-rail device — driven by MAX98357A BTL |
| Interface | Two terminals → **SPK+** and **SPK-** |
| Limits | 1 W rated. Amp can theoretically exceed 1 W into 8 Ω at 5 V; keep firmware volume moderate. Never connect either terminal to **GND** |

Speaker wiring is **not** drawn on `docs/wiring/Tiny Engineer.drawio`. Electrical rule is still: speaker ↔ SPK+/SPK- only.

## 0.91" 128×32 OLED (SSD1306, I2C)

| Field | Value |
| --- | --- |
| Exact model | Generic 0.91" 128×32 SSD1306 I2C OLED |
| Quantity | 1 |
| Purpose | Status / test UI |
| Operating voltage | Module **VCC** from ESP32 **3V3** (confirmed in [`docs/wiring`](../wiring/Tiny%20Engineer.drawio.png)) |
| Interface | I2C on the shared bus |
| Address | **`0x3C`** (`OLED_ADDRESS` in firmware). Alternate 0x3D exists on some modules if the ADDR jumper is changed — not used here |
| Resolution | 128×32 (`OLED_WIDTH` / `OLED_HEIGHT`) |
| Important pins | As drawn: **VCC**, **GND**, **SDA**, **SCK** (that **SCK** pad is I2C SCL) |
| Firmware notes | `SSD1306_SWITCHCAPVCC`; display rotated **180°** (`setRotation(2)`). Missing OLED is **non-fatal** in the bring-up test |
| Limits | 3.3 V logic. Do not hang this module on the servo +5V rail unless a specific 5 V-tolerant module is verified (**current wiring is 3V3**) |

## Adafruit 5993 USB-C breakout

| Field | Value |
| --- | --- |
| Exact model | Adafruit 5993 — USB Type C Vertical Breakout, downstream connection |
| Quantity | 1 |
| Purpose | Sole robot USB-C: **+5V power** and **programming / CDC** |
| Operating voltage | USB **VBUS** = 5 V |
| Electrical | Two 5.1 kΩ CC resistors request 5 V and **up to ~1.5 A**. Actual current is whatever the **upstream source** can give |
| Interface | **VBUS**, **GND**, **D+**, **D−**. Wire D−→ESP32 GPIO18, D+→ESP32 GPIO19 |
| Important pins | Drawing may show USB **5V** / **GND** only; also wire **D+/D−** to native USB |
| Limits | **Not** a USB-PD voltage converter. It does not step 9 V/12 V/20 V down to 5 V. Prefer a **5 V / ≥2 A** host — see [power.md](power.md) |

Prefer a final 5 V supply of **at least ~2 A** with margin if several servos move while audio plays.

## Mechanical / RF notes for firmware and CAD

- Keep metal and dense plastic **off** the ESP32 ceramic antenna area.
- Servo horns and end stops: start from `SERVO_SPECS` in [`include/servos.h`](../../include/servos.h); tune after installation if needed. Bench-only test band remains 75–105°.
- GPIO18/19 are native USB via the 5993 data wires. Do not reassign them while using USB CDC for flash/serial.

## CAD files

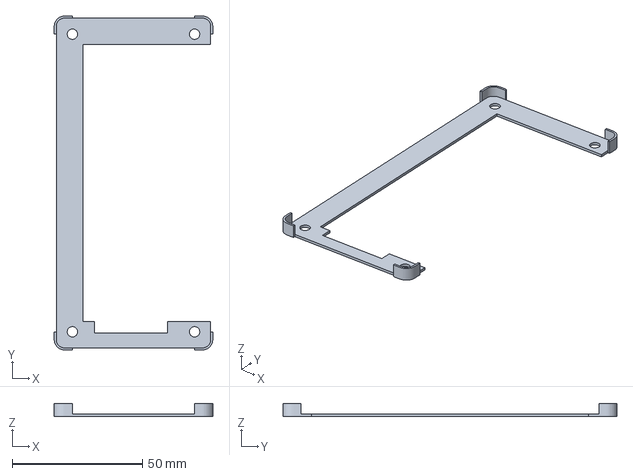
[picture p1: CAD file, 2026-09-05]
3d_models/parts/DeskPad.3mf
61.0 x 128.4 x 5.00 mm

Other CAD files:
3d_models/cad/TinyEngineer.f3d

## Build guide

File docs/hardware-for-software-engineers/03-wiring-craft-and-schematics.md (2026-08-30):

# Wiring craft and schematics

Software has stack traces. Hardware has smoke. Most beginner failures aren't mysterious — they're a loose GND, swapped data lines, or a wire that pulled out when you closed the case. This chapter is about making connections you can trust and reading the diagram — Tiny Engineer's drawing is the practice artifact.

---

## Dupont / jumper — the connector this project uses

**Dupont** (jumper) = plastic housing on a pin header. One wire, one pin. That's the whole connector story here.

This build uses Dupont on **servos**, **OLED**, and **ESP32** so those parts unplug and swap if something dies. Servo cables already end in a 3-pin plug (signal / +5 V / GND — often yellow, red, brown; **verify your batch**). That plug seats on Dupont-style headers.

> **If you've written backend code…** Dupont is like a typed port: one pin, one job. Read the silkscreen. Wrong hole is a type error with smoke.

---

## Breadboard vs permanent wiring

**Breadboard** — spring clips, no solder. Great for blinking an LED. Wires pop out. Too bulky for this robot.

**This project needs permanent wiring** — soldered joints that survive being stuffed into a small printed body. Vibration and tight space kill breadboard builds.

**Practical split:**
- **Solder** the boards that stay in the robot: USB-C breakout, PCA9685 servo driver, audio amp, and the power/signal harness between them
- **Dupont** to ESP32, OLED, and servos — replaceable without a soldering iron
- Wire and **verify on the bench** (boot, I2C, one servo, audio) **before** routing into the shell. Debugging inside a closed chest is miserable

The Waveshare **ESP32-C3-Zero** used here ships with **male pins already soldered**. You still solder everything else that doesn't come with headers you can plug into: USB socket/breakout, servo controller, audio board, and the wires that join those modules.

---

## Strain relief and color

Don't tug on solder joints. Zip-tie or clip USB and servo cables so a yank hits the tie, not the pad.

Color is habit, not law: red ≈ positive, black/brown ≈ GND, yellow/orange/green ≈ signal. **Trust labels and a multimeter, not memory.**

---

## Reading schematics and block diagrams

You don't need a full EE schematic. You need the **block diagram** mindset:

- **Boxes** = modules (ESP32, PCA9685, OLED, amp)
- **Lines** = nets (SDA, SCL, 5V, GND)
- **Same net name** = must be connected together

Tiny Engineer's map: [Tiny Engineer.drawio.png](../wiring/Tiny%20Engineer.drawio.png).

> **If you've written backend code…** The PNG is an architecture diagram. [wiring.md](../hardware/wiring.md) is the connection table. [pinout.md](../hardware/pinout.md) is GPIO allocation. Same system, three views.

**How to use the diagram:**
1. Find the ESP32 box — trace I2C to PCA9685 and OLED
2. Trace 5 V from USB breakout to each power consumer
3. Trace 3.3 V from ESP32 to logic VCC pins
4. Confirm GND stars at the USB breakout and fans out

Don't memorize — **trace the path** for whatever you're debugging.

---

## Soldering: enough to not fear it

You will solder. The ESP32 headers are already done; USB, PCA9685, audio, and the interconnects are not.

Basics:
- **Iron** ~350°C for lead-free (follow your solder's label)
- **Tin the pad and the wire**, then join — don't dump a blob on one side
- **Continuity check** after — multimeter beep between pad and wire end

Bad solder looks dull and grainy (cold joint). Good joint is shiny and concave. YouTube "through-hole soldering" beats a paragraph here.

---

## What not to do on first power-up

- Don't power servos before common GND is verified
- Don't connect MAX98357A **SPK−** to GND (bridge-tied load — see [Ch. 04](04-buses-and-protocols.md))
- Don't force a tight 3D-printed pocket onto a servo — ream or reprint instead

Assembly checks before first power: [wiring.md](../hardware/wiring.md) — read that when you're actually wiring, not this chapter.

---

## In Tiny Engineer

Use [Tiny Engineer.drawio.png](../wiring/Tiny%20Engineer.drawio.png) as your map and [wiring.md](../hardware/wiring.md) as your checklist. This guide doesn't duplicate the connection table.

**Bench bring-up order** (wiring mindset):
1. USB power + GND only → ESP32 boots (LED, serial)
2. Add I2C devices → serial shows PCA9685 found
3. Add one servo on one channel → `/test/servo` moves it
4. Add audio, OLED, remaining servos
5. Install into printed parts

**OLED naming trap:** the pad labeled **SCK** on many OLED modules is I2C **SCL**, not SPI clock. Easy to misread if you're used to SPI docs.

---

**Next:** [Buses and protocols](04-buses-and-protocols.md)

**Reference:** [hardware/wiring.md](../hardware/wiring.md) · [wiring/Tiny Engineer.drawio.png](../wiring/Tiny%20Engineer.drawio.png)

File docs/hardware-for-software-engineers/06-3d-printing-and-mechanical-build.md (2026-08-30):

# 3D printing and mechanical build

Software lives in repos; hardware lives in **enclosures**. 3D printing is how you turn CAD into a physical body — layer by layer, with tolerances that bite if you ignore them. If you've never printed, this chapter is the missing semester: materials, fit, CAD source, and not destroying a servo by forcing it into a tight pocket. **Tiny Engineer** is the case study; the skills transfer to any printed mount or case.

---

## FDM printing in 60 seconds

**FDM** (Fused Deposition Modeling) — the common hobby printer type — melts plastic filament layer by layer.

Knobs that matter:

| Parameter | Typical starting point | What it affects |
| --- | --- | --- |
| **Layer height** | **0.16 mm** (used for the tested prints) | Surface quality vs speed |
| **Infill** | 20–30% structural | Strength vs print time |
| **Orientation** | As in the `.3mf` | Overhangs; supports (see below) |
| **Material** | **PLA** is enough; PETG also works | Ease vs toughness |

### Supports

Plastic cannot print in mid-air. An **overhang** (a surface that sticks out with nothing under it) needs **supports** — extra throwaway plastic the slicer builds like scaffolding, then you snap or dissolve off.

Supports leave scars, use filament, and make small holes and servo pockets messy.

**This project's parts are designed and oriented so they print with no supports.** Keep the `.3mf` orientation. Rotate a part "to look nicer on the bed" and you may suddenly need supports and get ugly undersides.

### What printer

All parts were printed and test-fitted on a **Creality Ender 3 V3 SE**. You should be able to print them on **any FDM printer** that can run PLA (or PETG) at typical hobby settings — the files are not locked to that machine.

---

## Materials: PLA vs PETG

**PLA is sufficient** for the whole robot — desk use, indoor, this design. **PETG also works** if that's what you have (tougher, a bit stringier to print). Pick one spool if you care about color match.

| Material | Use here |
| --- | --- |
| **PLA** | Default. Fine for servo pockets, chair, desk, props |
| **PETG** | Also fine. Slightly stronger; not required |

Antenna zone: keep plastic thin/light near the ESP32 ceramic antenna. No metal paint, no foil wrap "for aesthetics."

---

## Tolerance and "it doesn't fit"

The models are **prepared with clearance** so printed parts and hardware (servos, screws) are meant to **fit together** without sanding as the happy path. 3D printing is still approximate — holes shrink, first layers bulge ("elephant's foot"), printers vary.

**If a servo doesn't slide in:**
- Don't force it — gears aren't meant to take press-fit stress
- Ream with a drill bit by hand, or
- Sand lightly, or
- Open the pocket in CAD and re-export

> **If you've written backend code…** Printed holes are like JSON numbers — `2.0` isn't exactly 2.0 after float serialization. These files already budget slack; a badly calibrated printer can still eat it.

**Screws:** assembly uses **2 mm diameter** screws, no glue. Exact lengths/counts aren't fully documented yet — use the [parts table](../../3d_models/README.md) as inventory and test fit as you go.

---

## Editing the CAD — Fusion 360

### Source vs export

| File | What it is |
| --- | --- |
| [`cad/TinyEngineer.f3d`](../../cad/TinyEngineer.f3d) | **Parametric source** — full assembly in Autodesk Fusion |
| [`3d_models/parts/*.3mf`](../../3d_models/parts/) | **Exported meshes** — what the printer eats |

> **If you've written backend code…** `.f3d` is the repo. `.3mf` is the release binary. Don't edit `.3mf` as source — edit Fusion, re-export.

### When to open Fusion

- Servo pocket too tight/loose after first print
- Different micro servo dimensions (not just HD-1370A)
- Cable routing channel for your wiring harness
- Antenna keep-out adjustment
- Desk/chair scale for your desk

Parts are designed around **HD-1370A** dimensions and **2 mm** screws. Swapping servos usually means CAD edits, not just firmware.

### Export workflow

1. Open `TinyEngineer.f3d` in Fusion (free personal license exists)
2. Edit the body you need
3. Export that body to `.3mf` in `3d_models/parts/` (or your fork)
4. Print and test fit

Alternatives (FreeCAD, Onshape) can work but project source is Fusion.

---

## Mechanical assembly principles

Full step-by-step SOP is still a doc gap — these principles keep you out of trouble:

### Servo installation

- **Orientation matters** — spline exit direction must match linkage. Check before screwing pocket closed
- **Screw horn with servo at center** — boot firmware or `/test/servo` to 90° first
- **Don't over-tighten horn screw** — strips plastic hub

### Range of motion before closing shell

Command each joint through safe range ([robot-movement.md](../robot-movement.md)). Listen for buzzing (stall). Adjust horns or firmware limits before trapping servos in plastic.

### USB and service access

Leave the USB-C breakout reachable for reflash. You'll flash again. Trust me.

### Antenna clearance

ESP32-C3-Zero ceramic antenna needs air. Don't bury it against metal or a thick plastic wall. Wi-Fi is the control plane for your agent.

### No glue policy

Screws only — disassembly for fixes. Like modular monolith vs ball of mud.

### Desk scene

Chair, desk, laptop, bell, lamp, mug — cosmetic storytelling. Print order doesn't matter much; prioritize robot body + servos for bring-up.

Part list: [3d_models/README.md](../../3d_models/README.md).

---

## Print while you wait — parallel path

Electronics can ship slow. Start printing **structural parts** (chest, head, chair) while reading [Ch. 04](04-buses-and-protocols.md) and wiring on a bench without the shell. Parallelism beats serial idle time.

---

**Next:** [Power budgets and safety](07-power-budgets-and-safety.md)

**Reference:** [3d_models/README.md](../../3d_models/README.md) · [cad/TinyEngineer.f3d](../../cad/TinyEngineer.f3d) · [robot-movement.md](../robot-movement.md)

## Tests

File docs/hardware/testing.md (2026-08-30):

# Hardware testing

Firmware is [`src/main.cpp`](../../src/main.cpp). Boot **inits** hardware and starts HTTP. Demos (OLED, tones, servo sweep) run on demand via REST. Helpers:

- [`src/hardware/rgb.cpp`](../../src/hardware/rgb.cpp)
- [`src/display/oled.cpp`](../../src/display/oled.cpp) (init/boot/test: `oled_init.cpp`, `oled_boot.cpp`, `oled_test.cpp`)
- [`src/network/wifi_connect.cpp`](../../src/network/wifi_connect.cpp)
- [`src/audio/audio.cpp`](../../src/audio/audio.cpp)
- [`src/hardware/pca9685_servos.cpp`](../../src/hardware/pca9685_servos.cpp)
- [`src/http/http_server.cpp`](../../src/http/http_server.cpp), [`src/http/test_handlers.cpp`](../../src/http/test_handlers.cpp)

Constants: [`include/pins.h`](../../include/pins.h). Wi-Fi credentials are saved in NVS and configured only in setup AP mode (first boot, or after factory reset + power-cycle).

Build/flash: project root README (`pio run`, `pio run -t upload`, serial 115200). Physical board is **Waveshare ESP32-C3-Zero**; PlatformIO env name is `esp32-c3-devkitm-1`.

## What boot covers

| Subsystem | How |
| --- | --- |
| Built-in WS2812 | Green ready (GPIO10) |
| I2C init | `Wire.begin` on GPIO0/GPIO1 |
| PCA9685 | Probe `0x40` early; park neutral; optional OE on GP5 |
| OLED | Probe `0x3C`, init (optional) |
| Wi-Fi | STA connect from saved NVS credentials, or setup AP `TinyEngineer-XXXX` when unset/failed; mDNS `{hostname}.local` after STA connect |
| MAX98357A / I2S | `I2S.begin` 44.1 kHz 16-bit stereo |
| Servos | Smooth move to mid (or sleep pose) at 35°/s |
| HTTP | Port 80 if Wi-Fi connected |
| Success | Dim green RGB during init; then animation LED (see below) |

## Expected boot sequence

1. Serial banner `TINY ENGINEER`
2. `Starting I2C` / `SDA = GP0` / `SCL = GP1`
3. `Checking PCA9685 at 0x40...` → **must** succeed; all channels parked at mid
4. `Checking OLED at 0x3C...` → found or `ERROR: OLED not found` (continues)
5. Settings load from NVS (`loading` = `progress` or `sleep_inertia`)
6. **Progress loading (default):** OLED progress steps (Display → WiFi → Servos → Audio → Storage → Ready), then large full-width IP (or `No IP`) for 3 s, then idle eyes
7. **Sleep inertia loading:** closed eyes during init; smooth move to sleep pose if `welcome` is on; slow eye open + blinks (~5.5 s). Head/neck wave only if `welcome` is on; otherwise eyes only
8. `WIFI SETUP` on serial — connect OK + IP, open setup AP, or saved credentials failed (setup AP for reconfiguration)
9. `Starting MAX98357A` → `I2S OK`
10. `Centering servos` — smooth move to per-channel mid (progress path only; skipped if sleep pose already applied)
11. `ROBOT READY`
12. RGB fades to white over 1 s if `welcome` runs (Wi-Fi OK and setting enabled), or fades off if idle
13. If Wi-Fi OK: `HTTP: http://<ip>/`, `HTTP: http://tiny-engineer.local/`, and `/health` URLs on serial
14. If setup AP active: `HTTP setup: http://192.168.4.1/config` on serial; OLED rotates setup instructions

`loop()` pumps the HTTP server and updates animation RGB fades. No audio/OLED/servo/LED demos until a POST.

## Animation RGB

During normal operation the onboard WS2812 tracks the active animation (not boot green):

| Animation | LED |
| --- | --- |
| `typing`, `reading`, `thinking`, `welcome`, `ring`, `wakeup` | White |
| `attention`, `error`, `dead` | Pulsing red (10%↔100%, 1.5 s cycle) |
| `abort` | Solid red |
| `none`, `sleep` | Off |

State changes fade over **1 s** (see [`docs/api.md`](../api.md#rgb-led)). Trigger via `POST /anim?name=…` or Cursor hooks.

OLED shows matching status strings when the panel is present (progress loading: WiFi step labels; sleep inertia: eyes only).

## HTTP tests

API reference: [`docs/api.md`](../api.md).

Base URL is the board IP or `http://tiny-engineer.local` (2.4 GHz STA). Tests have side effects — use **POST**, not GET.

```bash
# Health
curl http://tiny-engineer.local/health

# Tones 500 / 700 / 1000 Hz
curl -X POST http://tiny-engineer.local/test/audio

# OLED title / HELLO / X in a box
curl -X POST http://tiny-engineer.local/test/screen

# Servos 90 → 105 → 75 → 90 (channels 0–4)
curl -X POST http://tiny-engineer.local/test/movement

# Onboard WS2812 R → G → B → white → off, then back to current animation LED
curl -X POST http://tiny-engineer.local/test/led

# One servo smooth move to angle (~40°/s; index 0–4, angle 0–180)
curl -X POST "http://tiny-engineer.local/test/servo?index=0&angle=90"
```

| Method | Path | Body |
| --- | --- | --- |
| `GET` | `/` | HTML endpoint index |
| `GET` | `/auth` | Auth status (`ok`, `required`) — always public |
| `GET` | `/health` | Health JSON (`ok`, `uptime_ms`, `free_heap`, `heap_size`, `cpu_temp_c`, `wifi`, `oled`) |
| `GET` | `/settings` | Persistent settings (`sleep_timeout`, `hostname`, `volume`, `welcome`, `serial_log`, `continuous_timeout`, `loading`, `access_token_set`, `wifi_configured`, `wifi_ssid`, `wifi_password_set`) |
| `POST` | `/settings?...&wifi_ssid=&wifi_password=` | Update NVS settings; WiFi params setup-AP-only and tested before save; `reboot_required` if hostname changed |
| `POST` | `/settings/reset` | Factory reset all settings to defaults (clears WiFi); power-cycle to reopen setup AP |
| `POST` | `/test/audio` | `{"ok":true,"test":"audio"}` after `runSoundTest()` |
| `POST` | `/test/screen` | `{"ok":true,"test":"screen"}` after `runOledTest()` |
| `POST` | `/test/movement` | `{"ok":true,"test":"movement"}` after `runServoTest()` |
| `POST` | `/test/led` | `{"ok":true,"test":"led"}` after `runRgbTest()` |
| `POST` | `/test/servo?index=&angle=` | `{"ok":true,"test":"servo","index":N,"angle":A}` after `moveServoSmooth()` |

GET on a test path returns `405`. Bad `/test/servo` or `/settings` params return `400`. Missing/wrong Bearer when auth enabled returns `401`. Control APIs return `503` when WiFi credentials are not saved. Unknown path returns `404`. JSON `Content-Type`. Handlers block until the test finishes; the OLED returns to `ROBOT READY` after.

HTTP runs on STA when connected, or on setup AP at `192.168.4.1` during provisioning.

## Failures

| Serial / OLED | Meaning | Check |
| --- | --- | --- |
| OLED `ERROR: OLED not found` then rest of boot runs | Nothing ACK’d at `0x3C` | OLED **VCC=3V3**, GND, SDA=GP0, **SCK**=GP1, common ground, address jumper still 0x3C |
| OLED found but `ERROR: OLED initialization failed` | ACK then `display.begin` failed | Wiring/power glitch, wrong size module, I2C noise |
| OLED shows `Join this WiFi` / AP name, then `Then open` / `192.168.4.1` | Setup AP mode active | Connect to the shown AP, open `http://192.168.4.1/config`, enter home WiFi credentials |
| OLED `WiFi failed` then setup AP | Saved STA credentials failed | Join setup AP, open `http://192.168.4.1/config`, enter home WiFi again |
| `ERROR: PCA9685 not found` + red RGB + **hang** | Nothing ACK’d at `0x40` | PCA9685 **VCC=3V3** (not V+), GND, SDA/SCL, I2C address pads, +5V not required for the ACK but needed later for motion |
| `ERROR: I2S initialization failed` + red RGB + **hang** | `I2S.begin` failed | GPIO2/3/4 not shorted to 5V/GND; pin constants; USB CDC still alive so you can read the line |
| I2S OK but `POST /test/audio` is silent | Amp or speaker | MAX98357A **Vin**=USB 5V, GND, GP2/3/4 → BCLK/LRC/DIN, speaker on **SPK+ / SPK-** (not on the PNG, not GND) |
| Servos silent / twitch / ESP32 resets during `POST /test/movement` | Power or SIG | **V+** is +5V, SIG on ch 0–4, **common GND**, supply current — see [power.md](power.md) |
| RGB never goes green | GPIO10 LED path | Board is C3-Zero (LED on GPIO10). Do not expect an external NeoPixel |

OLED absence and Wi-Fi failure are **soft** fails. PCA9685 and I2S failures **halt** in `while (true)`.

## Power during the servo test

All five servos move together on `POST /test/movement`. A weak USB port often dies **here**. If the serial port drops exactly when that POST runs: treat as brownout, not a PWM bug. Boot only parks at 90°, which is much lighter.

## What this test does not prove

- That tuned mechanical limits match a particular physical build (start from `SERVO_SPECS`; adjust after assembly)
- BLE (out of scope)
- Speaker power rating vs max amp output
- I2C at high speed

Related: [pinout.md](pinout.md), [wiring.md](wiring.md), [servos.md](servos.md).

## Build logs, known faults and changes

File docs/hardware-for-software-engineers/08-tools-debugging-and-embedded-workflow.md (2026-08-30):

# Tools, debugging, and embedded workflow

You don't need an oscilloscope to do useful hardware. You need patience, a multimeter, serial logs, and the discipline to bisect problems like you would in production. This workflow applies to any MCU project; Tiny Engineer is what you'll bench-debug first.

---

## Minimal tool kit

| Tool | Why |
| --- | --- |
| **Multimeter** | DC voltage, continuity beep |
| **USB cable (data)** | Charge-only cables cause "upload failed" existential crisis |
| **5 V / ≥ 2 A supply** | Known-good power |
| **Screwdrivers** | 2 mm screws, horn screws |
| **Soldering iron** (optional) | If your wiring isn't all Dupont |
| **Zip ties / tape** | Strain relief |

Nice later: helping hands, flux, desolder braid. Not day one.

---

## Multimeter — two modes you'll use

**DC voltage (V⎓):** probe between 5V and GND — should be ~5 V under load. Probe 3V3 and GND on ESP32 — ~3.3 V. If 5 V collapses when servos move, supply or wiring.

**Continuity (beep):** power **off** — verify GND nets connect, verify you're not shorting 5V to GND before first power.

You don't need to measure µs PWM pulses. If angles are wrong, suspect firmware limits or horn alignment before reaching for scope rental.

---

## Serial monitor — your stdout

```bash
pio device monitor
```

115200 baud. Boot logs tell you:
- PCA9685 found or not
- OLED found or not
- Wi-Fi state
- Init errors

> **If you've written backend code…** Serial is structured logging before structured logging existed on the device. Read it before guessing.

Upload and monitor details: [getting-started.md § Flash](../getting-started.md#4-flash).

---

## PlatformIO — npm for firmware

From project root:

| Command | Does |
| --- | --- |
| `pio run` | Build firmware |
| `pio run -t upload` | Flash firmware + LittleFS (via post-script) |
| `pio run -t uploadfs` | Filesystem only — if audio silent but servos work |
| `pio device monitor` | Serial |
| `pio device list` | Find port when multiple USB devices |

`platformio.ini` is like `package.json` + Makefile — board target, libraries, upload speed.

**Board name vs physical board:** `esp32-c3-devkitm-1` is the PlatformIO target; physical board is Waveshare C3-Zero. See [Ch. 02](02-microcontrollers-and-esp32.md).

---

## Divide-and-conquer bring-up

Don't assemble everything, power on, and hope. **Bisect** like a failing integration test:

| Stage | Verify |
| --- | --- |
| 1. USB power only | ESP32 boots, serial output, dim green LED |
| 2. + I2C (PCA9685, OLED) | Serial lists devices; PCA9685 required |
| 3. + one servo on ch 0 | `/test/servo?index=0&angle=90` moves it |
| 4. + all servos | Each channel, safe ranges |
| 5. + I2S amp + speaker | Audio test endpoint or animation with sound |
| 6. + mechanical shell | Range of motion, no binding |

Failure table and expected boot sequence: [testing.md](../hardware/testing.md).

---

## HTTP test harness

Once on Wi-Fi, the robot exposes **integration-test-style endpoints**:

- `/health` — alive, CPU temp
- `/test/servo` — single joint
- Web UI — hardware tests without memorizing curl

> **If you've written backend code…** `/test/*` is a manual test harness you hit before E2E. Use it before calling the robot from Cursor hooks.

API shapes: [api.md](../api.md). Agent integration comes **after** hardware works: [integration.md](../integration.md).

---

## Hardware vs software — where to look

| Clue | Likely layer |
| --- | --- |
| Never boots, no serial | Power, USB data wiring, bricked flash |
| Boots, PCA9685 fail | I2C wiring, address, missing chip |
| Boots, resets on motion | Power supply current |
| Boots, one servo dead | That channel's signal or servo |
| Wi-Fi flaky | Antenna clearance, 2.4 GHz only, router |
| Audio silent | I2S wiring, LittleFS not uploaded, SPK+/SPK− |
| Angles wrong but motion OK | Horn alignment, safe range tuning |

When two things changed, revert one. Hardware debugging punishes batch changes like production outages.

---

## Common beginner mistakes (this project)

| Mistake | Consequence |
| --- | --- |
| Swapped SDA/SCL | No I2C devices |
| OLED SCK wired as SPI clock confusion | Same — it's SCL |
| Servos on 3.3 V | Brownout / dead LDO |
| VCC/V+ jumpered on PCA9685 | Logic or servo damage |
| SPK− to GND | Bad audio, possible amp damage |
| Charge-only USB cable | Upload fails |
| Weak 1 A charger | Resets on animation |
| Horn aligned at wrong angle | Binding, weird rest pose |
| Antenna blocked | `.local` doesn't resolve, flaky HTTP |

---

## When things are "done enough"

You're ready for [getting-started.md § Prove it](../getting-started.md#6-prove-it) and agent hooks when:

- `/health` returns OK on Wi-Fi
- Each servo sweeps inside safe range without buzzing
- OLED shows IP (or you're OK without it)
- At least one animation with audio works
- No reset during simultaneous servo + sound

---

**Next:** [How it all fits together](09-how-it-all-fits-together.md)

**Reference:** [hardware/testing.md](../hardware/testing.md) · [getting-started.md](../getting-started.md) · [integration.md](../integration.md)

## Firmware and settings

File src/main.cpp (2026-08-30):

#include <Arduino.h>
#include <Wire.h>
#include <ESP_I2S.h>

#include "pins.h"
#include "hardware/rgb.h"
#include "hardware/chip_temp.h"
#include "display/oled.h"
#include "audio/audio.h"
#include "animation.h"
#include "animation/constants.h"
#include "animation/util.h"
#include "hardware/pca9685_servos.h"
#include "hardware/servo_wrapper.h"
#include "network/wifi_connect.h"
#include "http/http_server.h"
#include "settings.h"
#include "serial_log.h"
#include "sleep.h"
#include "boot/boot_loading.h"

namespace {

constexpr int kBootSteps = 6;

}  // namespace

void setup() {
  initServoOutputPin();

  Serial.begin(115200);
#if defined(CONFIG_SOC_USB_SERIAL_JTAG_SUPPORTED)
  // Non-blocking CDC writes (ESP32-C3/S3); classic UART0 has no such knob.
  Serial.setTxTimeoutMs(0);
#endif
  delay(1000);

  initSettings();

  initChipTemp();

  serialLogPrintln();
  serialLogPrintln("==========================");
  serialLogPrintln("TINY ENGINEER");
  serialLogPrintln("==========================");

  setRgb(0, 32, 0);

  serialLogPrintln();
  serialLogPrintln("Starting I2C");
  serialLogPrint("SDA = ");
  serialLogPrintln(I2C_SDA);
  serialLogPrint("SCL = ");
  serialLogPrintln(I2C_SCL);

  Wire.begin(
    I2C_SDA,
    I2C_SCL
  );

  delay(100);

  initPca9685();

  initOled();

  const bool sleepServos = bootSleepInertiaUsesServos();

  if (bootLoadingIsProgress()) {
    bootShowProgress(1, kBootSteps, "Display");
  } else {
    bootBeginSleepingFace();
  }

  if (sleepServos) {
    bootSnapSleepPose();
  }

  bootShowProgress(2, kBootSteps, "WiFi...");
  runWifiSetup();
  bootShowProgress(
    2,
    kBootSteps,
    wifiConnected() ? "WiFi OK" :
    wifiProvisioningMode() ? "WiFi setup" : "WiFi failed"
  );

  bootShowProgress(3, kBootSteps, "Servos");

  serialLogPrintln();
  serialLogPrintln(
    "Starting MAX98357A"
  );

  I2S.setPins(
    I2S_BCLK,
    I2S_LRC,
    I2S_DIN
  );

  if (!I2S.begin(
        I2S_MODE_STD,
        SAMPLE_RATE,
        I2S_DATA_BIT_WIDTH_16BIT,
        I2S_SLOT_MODE_STEREO
      )) {
    serialLogPrintln(
      "ERROR: I2S initialization failed"
    );

    showOledText(
      "I2S ERROR",
      "Init failed"
    );

    setRgb(64, 0, 0);

    while (true) {
      delay(1000);
    }
  }

  serialLogPrintln("I2S OK");
  bootShowProgress(4, kBootSteps, "Audio");

  initAudioStorage();
  bootShowProgress(5, kBootSteps, "Storage");

  if (!sleepServos) {
    serialLogPrintln("Centering servos");
    centerAllServos();
  }

  if (bootLoadingIsProgress()) {
    bootShowProgress(kBootSteps, kBootSteps, "Ready");
    if (wifiProvisioningMode()) {
      showProvisioningOled("Join this WiFi", wifiApSsid());
    } else {
      showBootIp(wifiConnected() ? wifiIpText() : "");
      delay(3000);
      showIdleScreen();
    }
  } else {
    bootRunSleepInertia();
    if (wifiProvisioningMode()) {
      showProvisioningOled("Join this WiFi", wifiApSsid());
    }
  }

  serialLogPrintln();
  serialLogPrintln("==========================");
  serialLogPrintln("ROBOT READY");
  serialLogPrintln("==========================");

  if (wifiConnected() && settingsWelcomeEnabled()) {
    setAnimation(AnimationId::Welcome);
  } else if (wifiConnected() && !settingsWelcomeEnabled()) {
    anim::parkHands(anim::TRANSITION_HAND_SPEED_DEG_S);
  } else if (wifiProvisioningMode()) {
    setRgb(0, 0, 64);
  } else {
    setRgbForAnimation(AnimationId::None, millis());
  }

  if (wifiConnected() || wifiProvisioningMode()) {
    startHttpServer();
  }
  initSleep();
}

void loop() {
  const uint32_t now = millis();
  pollWifi();
  pollHttpServer();
  updateProvisioningOled(now);
  updateAnimation();
  // After HTTP/anim so idle timestamp from this frame is not compared to a stale `now`.
  updateSleep(millis());
  updateRgb(now);
}

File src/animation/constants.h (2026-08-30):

#pragma once

#include <cstdint>

#include "hardware/servo_wrapper.h"
#include "servos.h"

namespace anim {

constexpr float TYPING_HAND_BAND_DEG = 15.0f;
constexpr float TYPING_HEAD_BAND_DEG = 10.0f;
constexpr float TYPING_SWAY_DEG = 5.0f;
constexpr float READING_HEAD_BAND_DEG = 10.0f;
constexpr float READING_NECK_SWAY_DEG = 10.0f;

constexpr float TRANSITION_TORSO_SPEED_DEG_S = 25.0f;
constexpr float TRANSITION_HAND_SPEED_DEG_S = 90.0f;

constexpr float TYPING_RIGHT_LOW =
  SERVO_SPECS[SERVO_HAND_RIGHT].min;
constexpr float TYPING_RIGHT_HIGH =
  SERVO_SPECS[SERVO_HAND_RIGHT].min + TYPING_HAND_BAND_DEG;
constexpr float TYPING_LEFT_LOW =
  SERVO_SPECS[SERVO_HAND_LEFT].max - TYPING_HAND_BAND_DEG;
constexpr float TYPING_LEFT_HIGH =
  SERVO_SPECS[SERVO_HAND_LEFT].max;

constexpr float TYPING_HEAD_LOW =
  SERVO_SPECS[SERVO_HEAD].min;
constexpr float TYPING_HEAD_HIGH =
  SERVO_SPECS[SERVO_HEAD].min + TYPING_HEAD_BAND_DEG;

constexpr float TYPING_BODY_MID =
  servoMid(SERVO_SPECS[SERVO_BODY]);
constexpr float TYPING_NECK_MID =
  servoMid(SERVO_SPECS[SERVO_NECK]);

constexpr float READING_HEAD_LOW =
  SERVO_SPECS[SERVO_HEAD].min;
constexpr float READING_HEAD_HIGH =
  SERVO_SPECS[SERVO_HEAD].min + READING_HEAD_BAND_DEG;
constexpr float READING_NECK_MID =
  servoMid(SERVO_SPECS[SERVO_NECK]);

constexpr float RING_HEAD_START =
  servoMid(SERVO_SPECS[SERVO_HEAD]) + 10.0f;
constexpr float RING_BODY_START = SERVO_SPECS[SERVO_BODY].min;
constexpr float RING_RIGHT_START = SERVO_SPECS[SERVO_HAND_RIGHT].max;
constexpr float RING_LEFT_START =
  SERVO_SPECS[SERVO_HAND_LEFT].max - 10.0f;
constexpr float RING_NECK_START =
  servoMid(SERVO_SPECS[SERVO_NECK]);
constexpr float RING_RIGHT_STRIKE =
  SERVO_SPECS[SERVO_HAND_RIGHT].min + 5.0f;
constexpr float RING_RIGHT_BOUNCE =
  SERVO_SPECS[SERVO_HAND_RIGHT].min + 20.0f;
constexpr float RING_HEAD_STRIKE = SERVO_SPECS[SERVO_HEAD].min;

constexpr float WELCOME_HEAD_UP =
  servoMid(SERVO_SPECS[SERVO_HEAD]) + 10.0f;
constexpr float WELCOME_HEAD_MID =
  servoMid(SERVO_SPECS[SERVO_HEAD]);
constexpr float WELCOME_HAND_REST =
  SERVO_SPECS[SERVO_HAND_RIGHT].min;
constexpr float WELCOME_HAND_RAISED =
  SERVO_SPECS[SERVO_HAND_RIGHT].max;
constexpr float WELCOME_HAND_WIGGLE_DEG = 8.0f;

constexpr float ATTENTION_BODY_MID =
  servoMid(SERVO_SPECS[SERVO_BODY]);
constexpr float ATTENTION_NECK_MID =
  servoMid(SERVO_SPECS[SERVO_NECK]);
constexpr float ATTENTION_HEAD_READY =
  servoMid(SERVO_SPECS[SERVO_HEAD]) + 6.0f;
constexpr float ATTENTION_HAND_LEFT_PARKED =
  SERVO_SPECS[SERVO_HAND_LEFT].max;
constexpr float ATTENTION_HAND_RIGHT_REST =
  SERVO_SPECS[SERVO_HAND_RIGHT].min;
constexpr float ATTENTION_HAND_RIGHT_RAISED =
  SERVO_SPECS[SERVO_HAND_RIGHT].min + 48.0f;
constexpr float ATTENTION_HAND_POINT =
  SERVO_SPECS[SERVO_HAND_RIGHT].min + 60.0f;
constexpr float ATTENTION_HUMAN_NECK_GLANCE_DEG = 4.0f;
constexpr float ATTENTION_HUMAN_HEAD_NOD_DEG = 2.0f;
constexpr float ATTENTION_LOOK_NECK_GLANCE_DEG = 6.0f;
constexpr float ATTENTION_LOOK_HEAD_NOD_DEG = 2.0f;
constexpr float ATTENTION_WAIT_HEAD_NOD_DEG = 3.0f;
constexpr float ATTENTION_WAIT_NECK_TILT_DEG = 4.0f;
constexpr float ATTENTION_WAIT_HAND_WAVE_DEG = 7.0f;

// Attention/error wait after audio before auto-finish to none.
constexpr uint32_t NON_CONTINUOUS_HOLD_MS = 60UL * 1000UL;

constexpr float ERROR_BODY_TASK_SIDE =
  servoMid(SERVO_SPECS[SERVO_BODY]) - 8.0f;
constexpr float ERROR_NECK_TASK_SIDE =
  servoMid(SERVO_SPECS[SERVO_NECK]) - 10.0f;
constexpr float ERROR_HEAD_CONCERNED =
  servoMid(SERVO_SPECS[SERVO_HEAD]) - 12.0f;
constexpr float ERROR_HAND_RIGHT_PRESENT =
  SERVO_SPECS[SERVO_HAND_RIGHT].min + 58.0f;
constexpr float ERROR_HAND_LEFT_TASK_POINT =
  SERVO_SPECS[SERVO_HAND_LEFT].max - 22.0f;
constexpr float ERROR_HELP_NECK_GLANCE_DEG = 10.0f;
constexpr float ERROR_AWAY_NECK_GLANCE_DEG = 4.0f;
constexpr float ERROR_HELP_HEAD_GLANCE_DEG = 3.0f;
constexpr float ERROR_WORRY_HEAD_NOD_DEG = 2.0f;

constexpr float ABORT_BODY_DISMISSIVE =
  servoMid(SERVO_SPECS[SERVO_BODY]) - 5.0f;
constexpr float ABORT_NECK_SIDE =
  servoMid(SERVO_SPECS[SERVO_NECK]) + 14.0f;
constexpr float ABORT_NECK_OTHER_SIDE =
  servoMid(SERVO_SPECS[SERVO_NECK]) - 6.0f;
constexpr float ABORT_HEAD_UP =
  servoMid(SERVO_SPECS[SERVO_HEAD]) + 16.0f;
constexpr float ABORT_HEAD_DIP =
  servoMid(SERVO_SPECS[SERVO_HEAD]) + 5.0f;

// Idle sleep / boot sleep-inertia: chin down, then rise to mid on wake.
constexpr float SLEEP_HEAD_DOWN_OFFSET_DEG = -20.0f;
constexpr float SLEEP_HEAD_DOWN =
  servoMid(SERVO_SPECS[SERVO_HEAD]) + SLEEP_HEAD_DOWN_OFFSET_DEG;
constexpr float SLEEP_HEAD_AWAKE =
  servoMid(SERVO_SPECS[SERVO_HEAD]);
constexpr float ABORT_HAND_RIGHT_UP =
  SERVO_SPECS[SERVO_HAND_RIGHT].max;
constexpr float ABORT_HAND_RIGHT_SHRUG =
  SERVO_SPECS[SERVO_HAND_RIGHT].max - 10.0f;
constexpr float ABORT_HAND_LEFT_UP =
  SERVO_SPECS[SERVO_HAND_LEFT].max - 55.0f;
constexpr float ABORT_HAND_LEFT_SHRUG =
  SERVO_SPECS[SERVO_HAND_LEFT].max - 43.0f;
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

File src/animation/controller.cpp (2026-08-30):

#include <Arduino.h>
#include <string.h>

#include "animation.h"
#include "animation/abort.h"
#include "animation/attention.h"
#include "animation/error.h"
#include "animation/registry.h"
#include "animation/util.h"
#include "audio/audio.h"
#include "display/eyes.h"
#include "hardware/rgb.h"
#include "hardware/servo_wrapper.h"
#include "network/wifi_connect.h"
#include "settings.h"
#include "sleep.h"
#include "serial_log.h"

namespace {

constexpr uint32_t MIN_ANIMATION_HOLD_MS = 1000;

AnimationId g_animation = AnimationId::None;
uint32_t g_animationStartedMs = 0;
uint32_t g_continuousStartedMs = 0;
bool g_hasPendingAnimation = false;
AnimationId g_pendingAnimation = AnimationId::None;

void applyAnimation(AnimationId id, uint32_t nowMs) {
  if (id != AnimationId::Attention) {
    stopAttentionPlayback();
  }
  if (id != AnimationId::Error && id != AnimationId::Dead) {
    stopErrorPlayback();
  }
  if (id != AnimationId::Abort) {
    stopAbortPlayback();
  }

  const ModeEntry* fromEntry = modeByAnimId(g_animation);
  const ModeEntry* entry = modeByAnimId(id);

  serialLogPrint("[anim] transition ");
  serialLogPrint(fromEntry->name);
  serialLogPrint(" -> ");
  serialLogPrintln(entry->name);
  anim::logServoSnapshot("pre-transition");

  // Raise head out of sleep pose before the new anim claims servos.
  // None / Sleep / Wakeup must keep chin-down (or own the rise).
  if (id != AnimationId::None &&
      id != AnimationId::Sleep &&
      id != AnimationId::Wakeup) {
    prepareSleepWakePose();
  }

  g_animation = id;
  g_animationStartedMs = nowMs;
  g_continuousStartedMs = nowMs;
  g_hasPendingAnimation = false;

  setEyeMode(entry->eyeMode, g_animationStartedMs);

  if (entry->startAnim != nullptr) {
    entry->startAnim(g_animationStartedMs);
  }

  setRgbForAnimation(id, nowMs);
  onAnimationApplied(id, nowMs);
}

bool animationHoldElapsed() {
  return (millis() - g_animationStartedMs) >= MIN_ANIMATION_HOLD_MS;
}

}  // namespace

void setAnimation(AnimationId id) {
  if (id == g_animation) {
    g_hasPendingAnimation = false;
    // Re-requesting the same continuous anim refreshes continuous_timeout
    // without restarting motion or the 1s min-hold clock.
    if (animationIsContinuous(id)) {
      g_continuousStartedMs = millis();
    }
    return;
  }

  if (animationHoldElapsed()) {
    applyAnimation(id, millis());
    return;
  }

  g_pendingAnimation = id;
  g_hasPendingAnimation = true;

  const uint32_t holdLeftMs =
    MIN_ANIMATION_HOLD_MS - (millis() - g_animationStartedMs);
  serialLogPrint("[anim] pending ");
  serialLogPrint(modeByAnimId(id)->name);
  serialLogPrint(" holdLeftMs=");
  serialLogPrintln(holdLeftMs);
}

void finishAnimation(uint32_t nowMs) {
  applyAnimation(AnimationId::None, nowMs);
}

AnimationId getAnimation() {
  return g_animation;
}

bool hasPendingAnimation() {
  return g_hasPendingAnimation;
}

AnimationId pendingAnimation() {
  return g_pendingAnimation;
}

bool animationIsContinuous(AnimationId id) {
  return modeByAnimId(id)->continuous;
}

const char* animationName(AnimationId id) {
  return modeByAnimId(id)->name;
}

bool parseAnimationName(const char* name, AnimationId& out) {
  const ModeEntry* entry = modeByName(name);

  if (entry == nullptr) {
    return false;
  }

  out = entry->animId;
  return true;
}

void updateAnimation() {
  const uint32_t now = millis();

  if (g_hasPendingAnimation && animationHoldElapsed()) {
    applyAnimation(g_pendingAnimation, now);
  }

  if (animationIsContinuous(g_animation)) {
    const uint32_t timeoutMs =
      settingsContinuousTimeoutMin() * 60UL * 1000UL;
    if ((now - g_continuousStartedMs) >= timeoutMs) {
      setAnimation(AnimationId::Attention);
    }
  }

  const ModeEntry* entry = modeByAnimId(g_animation);

  if (entry->updateAnim != nullptr) {
    entry->updateAnim(now);
  } else {
    updateAllServos();
  }

  if (!wifiProvisioningMode()) {
    updateEyes(now);
  }
}

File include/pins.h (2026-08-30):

#pragma once

#include <cstdint>

// =====================================================
// PINOUT (multi-architecture)
// =====================================================
// One source tree, two targets. The active pin map is selected by the
// IDF target macro that PlatformIO sets per board:
//   CONFIG_IDF_TARGET_ESP32C3  -> Waveshare ESP32-C3-Zero (RISC-V)
//   anything else              -> classic ESP32 devkit (D0WD-V3)
//
// C3 pads: GP9 (USB D-) and GP11 (boot strapping) stay free.
// Classic pads: flash-reserved GPIOs (6-11, 12, 15) and strapping
// pins (0, 2, 15) stay free. UART0 stays free for serial logging.

#if defined(CONFIG_IDF_TARGET_ESP32C3)

// ---- ESP32-C3-Zero (Waveshare) ----

// I2C -> PCA9685 + OLED
constexpr int I2C_SDA = 0;   // GP0
constexpr int I2C_SCL = 1;   // GP1

// I2S -> MAX98357A
constexpr int I2S_BCLK = 2;  // GP2
constexpr int I2S_LRC  = 3;  // GP3
constexpr int I2S_DIN  = 4;  // GP4

// Onboard WS2812 RGB (GRB byte order)
constexpr bool RGB_LED_PRESENT = true;
constexpr int RGB_LED_PIN = 10;

// PCA9685 output enable (active LOW). Optional: wire OE -> GP5.
constexpr bool PCA9685_OE_WIRED = false;
constexpr int PCA9685_OE_PIN = 5;

#else

// ---- Classic ESP32 devkit (esp32dev, D0WD-V3) ----

// I2C -> PCA9685 + OLED (standard devkit I2C header)
constexpr int I2C_SDA = 21;
constexpr int I2C_SCL = 22;

// I2S -> MAX98357A
constexpr int I2S_BCLK = 4;
constexpr int I2S_LRC  = 5;
constexpr int I2S_DIN  = 16;

// No onboard WS2812. Most devkits carry an active-LOW single-color
// LED on GPIO2, but GPIO2 is a strapping pin (LOW at reset forces
// download mode), so it is not driven by default. To use a wired
// active-HIGH LED: set RGB_LED_PRESENT = true and RGB_LED_PIN to
// the LED pad.
constexpr bool RGB_LED_PRESENT = false;
constexpr int RGB_LED_PIN = 2;

// PCA9685 output enable (active LOW). Optional: wire OE -> GP17.
constexpr bool PCA9685_OE_WIRED = false;
constexpr int PCA9685_OE_PIN = 17;

#endif

// =====================================================
// AUDIO
// =====================================================

constexpr int SAMPLE_RATE = 44100;

// =====================================================
// PCA9685 / SERVOS
// =====================================================

constexpr uint8_t PCA9685_ADDRESS = 0x40;

constexpr int SERVO_STEP_MS = 10;

// Boot centering / sleep-pose rate (deg/s)
constexpr float SERVO_BOOT_SPEED_DEG_S = 35.0f;

// Servo pulse range
constexpr int SERVO_MIN_US = 800;
constexpr int SERVO_MAX_US = 2200;

// =====================================================
// OLED
// =====================================================

constexpr int OLED_WIDTH  = 128;
constexpr int OLED_HEIGHT = 32;
constexpr uint8_t OLED_ADDRESS = 0x3C;
